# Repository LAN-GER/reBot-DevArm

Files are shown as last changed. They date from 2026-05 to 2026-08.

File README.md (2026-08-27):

# 🦾 reBot-DevArm: Open Source Robotic Arm for All Developers

<p align="center">
  reBot-DevArm Banner
</p>

<p align="center">
    <a href="https://certification.oshwa.org/cn000024.html">
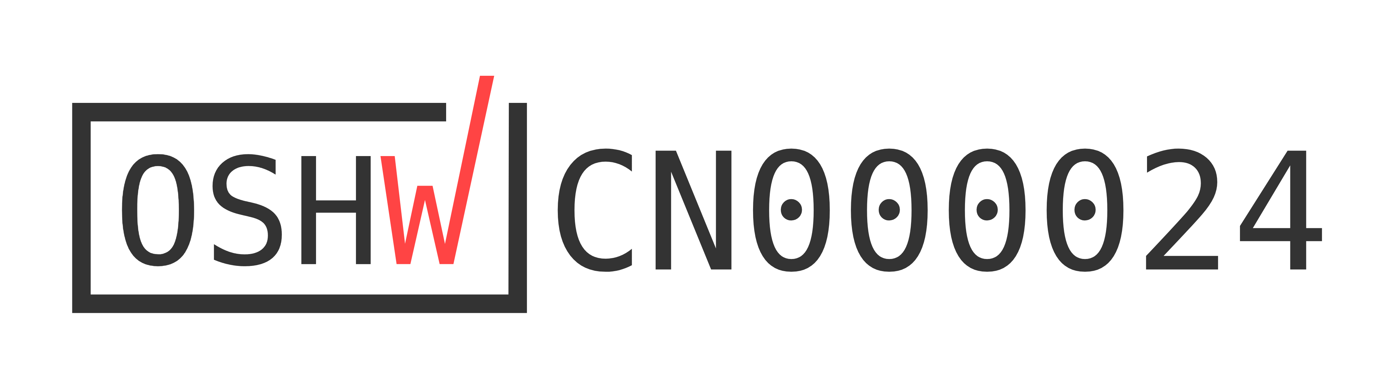
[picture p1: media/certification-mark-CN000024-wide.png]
  
</a>
</p>

<p align="center">
    <a href="./LICENSE">
    
    </a>
    
    </a>
    
    
    
    
</p>

<p align="center">
  <strong>🚀 100% Open Source · Embodied AI · Full Hardware + Software Stack</strong>
</p>

<p align="center">
  <strong>📦 Build your own robotic arm · 🧠 Learn robotics · 🏭 Deploy real applications</strong>
</p>

<table align="center">
  <tr>
    <td>
      <a href="https://www.youtube.com/watch?v=ONbpv3seiG8">
        
      </a>
    </td>
    <td>
      <a href="https://www.youtube.com/watch?v=ONbpv3seiG8">
        About The reBot Arm
      </a>
    </td>
  </tr>
</table>

<p align="center">
  <strong>
    <a href="./README_zh.md">简体中文</a> &nbsp;|&nbsp;
    <a href="./README.md">English</a> &nbsp;|&nbsp;
    <a href="./README_JP.md">日本語</a>&nbsp;|&nbsp;
    <a href="./README_Fr.md">français</a>&nbsp;|&nbsp;
    <a href="./README_es.md">Español</a>
  </strong>
</p>

<p align="center">
<a href="https://discord.gg/AbGuqJhDpQ">
    </a>
<a href="https://wiki.seeedstudio.com/robotics_page/">  
    </a>
</p>

<p align="center">
  <strong>🛒 Official Purchase</strong>
</p>

<table align="center" border="1" cellpadding="12" cellspacing="12">
  <tr>
    <td align="center" width="260" bgcolor="#FFF8F0">
      <b>&#x1F9FE; reBot Arm B601-DM</b><br><br>
      <a href="https://www.seeedstudio.com/reBot-Arm-B601-DM-Assembled-Kit-with-Power-Supply-Bundle.html" target="_blank">
        <big><b>&#x1F6D2; SeeedStudio Bazaar</b></big>
      </a>
        <a href="https://www.amazon.com/dp/B0H2TWVFSW" target="_blank">
        <big><b>&#x1F6D2; Amazon</b></big>
      </a>
      </a>
        <a href="https://de.aliexpress.com/item/1005012108314029.html" target="_blank">
        <big><b>&#x1F6D2; Aliexpress</b></big>
      </a>
    </td>
    <td align="center" width="260" bgcolor="#F0F4FF">
      <b>&#x1F9FE; reBot Arm B601-RS</b><br><br>
      <a href="https://www.seeedstudio.com/reBot-Arm-B601-RS-Bundle-p-6898.html" target="_blank">
        <big><b>&#x1F6D2;  SeeedStudio Bazaar</b></big>
      </a>
      <a href="https://www.aliexpress.us/item/3256812343811970.html?gatewayAdapt=deu2usa4itemAdapt" target="_blank">
        <big><b>&#x1F6D2; Aliexpress</b></big>
      </a>
    </td>
  </tr>
</table>

## 📖 Introduction

**reBot-DevArm (reBot Arm B601 DM and reBot Arm B601 RS)** is a robotic arm project dedicated to lowering the barrier to learning Embodied AI. We focus on **"True Open Source"** — not just the code, we unreservedly open source everything:
- 🦾 **Two versions of the robotic arm**：We will provide all open-source files for two versions of the robotic arm with the same appearance: **Robostride** and **Damiao**.
- 🛠️ **Hardware Blueprints**: Source files for sheet metal parts and 3D printed parts.
- 🔩 **BOM List**: Detailed down to the specifications and purchase links for every single screw.
- 💻 **Software & Algorithms**: Python SDK, ROS1/2, Isaac Sim, LeRobot, etc.

## Get Your Own reBot Arm

- We offer five kit options  at  [Seeedstudio.com](https://www.seeedstudio.com/reBot-Arm-B601-DM-Bundle.html) :
  - **Arm Body Motor Kit**: Includes only motors and wiring harnesses for the robotic arm.
  - **Arm Body Structural Kit**: Includes only mechanical structural components.
  - **Gripper Complete Kit**: Includes motors, wiring harnesses and structural components for the gripper.
  - **Full Kit**: Includes the complete set of the robotic arm body and gripper.
  - **Pre‑assembled Robotic Arm**: Fully assembled finished robotic arm.

- The Seeedstudio kit does not include a power adapter and C-clamps as standard accessories. This arrangement takes into account that users may power the unit via batteries or mount it with a custom DIY base. You may purchase a [power supply separately](https://www.seeedstudio.com/AC-DC-Power-Adapter-IEC-60320-C14-XT30-Female-24V-4-5A-1200mm-L190-W92-5-H36mm-p-6764.html) and [Power Cord](https://www.seeedstudio.com/reServer-AC-US-p-5052.html), or refer to the Mean Well power solution shown at the bottom of our [BOM](./hardware/reBot_B601_DM/readme.md#about-power-supply).

- You can also purchase the [Leader Arm](https://www.seeedstudio.com/Star-Arm-102-p-6765.html?qid=P2U7IG_yskyak5m_1776415593315) and [12V 10A Power Supply](https://www.seeedstudio.com/FY1209900-12V-10A-Power-Adapter-12V-10A-p-6496.html) You may also use the 12VDC power adapter of SO-ARM101 to supply power to the Leader.

-------------------
- For reBot Arm RS Version, We offer five kit options  at  [Seeedstudio.com](https://www.seeedstudio.com/reBot-Arm-B601-RS-Assembled-Kit-with-Gripper-p-6865.html) :
  - **Full Kit**: Includes the unassembled complete set of the robotic arm body and gripper.
  - **Pre‑assembled Robotic Arm**: Fully assembled finished robotic arm.

- We highly recommend using the [Meanwell 48V 12.5A](https://www.amazon.com/sspa/click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) power supply for the RS model. If you need stronger power to unlock its full performance, you may opt for a 48V 25A power adapter.
------------------

## 🗺️ Roadmap & Status

We are committed to continuously maintaining and adapting to mainstream robot development ecosystems. Below is our current adaptation progress and planned release schedule:

### reBot Arm B601 DM
| Supported Ecosystem | Status | Description / Estimated Release Date | Related Documentation |
| :--- | :---: | :--- | :--- |
| **Basic Motor Usage** | ✅ Completed | Basic motion control and API encapsulation | [Damiao Technology](https://wiki.seeedstudio.com/cn/damiao_series/) |
| **Open-Sourcing of the New STEP 3D Structural Parts and BOM** | ✅ Completed | STEP files for all parts in the new version, parts BOM, and reference prices for all machined components | [reBot Arm B601-DM BOM](./hardware/reBot_B601_DM/readme.md) |
| **Reference for Real Machine Performance Testing** | ✅ Completed | Performance Reference of Robotic Arm under Normal and Extreme Operating Conditions |[Performance Testing](./hardware/reBot_B601_DM/performance_testing/Performance_Testing.md) |
| **Assembly Video** | ✅ Completed | Ultra-detailed assembly steps and video | [Getting Started with reBot Arm B601-DM](https://wiki.seeedstudio.com/rebot_b601_dm_getting_started/) |
| **Python SDK** | ✅Continuously optimized, PRs welcome | One-stop integration of motor read/write and control for Robstride, Damiao, Mota, Gaoqing, Hexfellow and other motors. | [Getting Started with Motorbridge](https://motorbridge.seeedstudio.com) and [Web UI](https://rebot-devarm.w0x7ce.eu/)|
| **ROS2 Integration** | ✅ Completed | ROS2 integrated reBot Arm controller with support for kinematics, trajectory planning, and gravity compensation | [reBot Arm B601-DM ROS2 Integration Guide](https://wiki.seeedstudio.com/rebot_arm_b601_dm_ros2_integration/) |
| **Pinocchio Integration** |  ✅ Completed  | Adaptation to the Pinocchio framework, enabling forward/inverse kinematics and gravity compensation for the robotic arm | [Getting Started with Pinocchio for reBot Arm B601-DM](https://wiki.seeedstudio.com/rebot_arm_b601_dm_pinocchio_meshcat/) and [Github repo](https://github.com/vectorBH6/reBotArm_control_py) |
| **Isaac Sim Simulation** | 🚧 In Progress  | Import USD models and enable simulated teleoperation | [delay for add additional courses: 2026.06.20] |
| **LeRobot Integration** | ✅ Completed  | Adaptation to the Hugging Face LeRobot training framework | [Getting Started with LeRobot-based reBot Arm](https://wiki.seeedstudio.com/rebot_arm_b601_dm_lerobot/) |
| **Depth Camera Integration** | ✅ Completed  | Visual Grasping Demonstration Based on YOLO and Depth Camera | [Getting Started with Visual Grasping Demo](https://wiki.seeedstudio.com/rebot_arm_b601_dm_grasping_demo/) |
| **reSpeaker Voice Integration** | ✅ Completed  | Add reSpeaker Flex 4-mic array to build a voice-driven intelligent robot arm control system with spatial awareness | [reBot Arm B601-DM Voice Control](https://wiki.seeedstudio.com/control_rebot_arm_using_voice_with_respeaker_flex/) |
| **Gradual Updates of the Latest Algorithms** | ⏳ Planned | Mainstream algorithms will be updated progressively | Ongoing |
| **Launch of a Series of Completely Free Courses** | ⏳ Planned | Mainstream algorithms will be updated progressively | Ongoing |

#### Contributions from Developers 
| Supported Ecosystem | Authors | Description / Estimated Release Date | Related Documentation or Repository |
| :--- | :---: | :--- | :--- |
| **ROS2 (Humble), third_party integration, URDF / rebotarm_bringup** | [@danieldoradotalaveron-rb](https://github.com/danieldoradotalaveron-rb) | 1. **Passive diagnostics monitor** (`rebotarm_monitor_ros2`): `/diagnostics` overlay for `rqt_robot_monitor`, serial/CAN-aware aggregator;<br>2. **Safe park & shutdown**: Capture rest pose on connect, slow return on shutdown or `/rebotarm/park` to prevent sudden drop;<br>3. **Gravity compensation (smooth stop)**: MIT ramp-out when exiting gravity compensation to eliminate clack, jerk and instability during pos/vel handoff;<br>4. **Gamepad teleop with IK/FK and safety measures**: Gamepad control for end-effector via IK, live robot state visualization in RViz (simulation-only test);<br>5. **D405 eye-in-hand TF**: Xacro setup under `end_link` in `rebotarm_bringup` for RViz visualization & TF only (no driver/depth/intrinsics). Mount pose adjustable via launch file, bracket calibration not completed. Teleop FK/IK uses arm-only `fixend_core` URDF, full xacro for RSP/RViz. | [rebotarm_monitor_ros2](https://github.com/danieldoradotalaveron-rb/rebotarm_monitor_ros2)、[reBotArmController_ROS2](https://github.com/danieldoradotalaveron-rb/reBotArmController_ROS2) |

### reBot Arm B601 RS

| Supported Ecosystem | Status | Description / Estimated Release Date | Related Documentation |
| :--- | :---: | :--- | :--- |
| **Basic Motor Usage** | ✅ Completed | Basic motion control and API encapsulation | [Robstride](https://wiki.seeedstudio.com/cn/robstride_control/) |
| **Open-Sourcing of the New STEP 3D Structural Parts and BOM** | ✅ Completed | STEP files for all parts in the new version, parts BOM, and reference prices for all machined components | [reBot Arm B601-RS BOM](./hardware/reBot_B601_RS/README.md) |
|**Getting Started**| ✅ Completed | Quick start of B601-RS| [Getting Started with reBot Arm B601-RS](https://wiki.seeedstudio.com/rebot_b601_rs_getting_started/) |
| **Assembly Video** | ✅ Completed | Ultra-detailed assembly steps and video | [reBot Arm B601-RS Assembly Video](https://wiki.seeedstudio.com/rebot_b601_rs_getting_started/) |
| **ROS2 (Humble)** | ✅ Completed | ROS2 integrated reBot Arm controller with support for kinematics, trajectory planning, gravity compensation and MoveIt2 | [reBot Arm B601-DM ROS2 Integration Guide](https://wiki.seeedstudio.com/rebot_arm_b601_rs_ros2_integration/) |
| **LeRobot Integration** |✅ Completed| Adaptation to the Hugging Face LeRobot training framework | [Getting Started with LeRobot-based reBot Arm](https://wiki.seeedstudio.com/rebot_arm_b601_rs_lerobot/) |
| **Pinocchio Integration** | ✅ Completed | Adaptation to the Pinocchio framework, enabling forward/inverse kinematics and gravity compensation for the robotic arm | [Getting Started with Pinocchio for reBot Arm B601-DM](https://wiki.seeedstudio.com/rebot_arm_b601_rs_pinocchio_meshcat/) and [Github repo](https://github.com/vectorBH6/reBotArm_control_py) |
| **Depth Camera Integration** | ✅ Completed  | Visual Grasping Demonstration Based on YOLO and Depth Camera | [Getting Started with Visual Grasping Demo](https://wiki.seeedstudio.com/rebot_arm_b601_dm_grasping_demo/) |
| **Isaac Sim Simulation** |✅ Completed  | Import USD models and enable simulated teleoperation | [Github Repo](https://github.com/Seeed-Projects/reBot-Isaacsim) |
| **Gradual Updates of the Latest Algorithms** | ⏳ Planned | Mainstream algorithms will be updated progressively | On going |
| **Launch of a Series of Completely Free Courses** | ⏳ Planned | Mainstream algorithms will be updated progressively | Ongoing |

---

## ⚙️ Hardware Specifications

reBot-DevArm is designed for desktop Embodied AI applications, balancing payload capacity with flexibility.

| Parameter | reBot Arm B601-DM | reBot Arm B601-RS|
| :--- | :--- | :--- |
| **Payload** | 1.5kg | **2.5kg** |
| **Recommended Workspace** | 70% arm reach workspace | 70% arm reach workspace |
| **Max Reach** | 767 mm | **754 mm** |
| **Weight** | **Approx. 4.5 kg** | Approx. 6.7 kg |
| **Repeatability** | < 0.2 mm | < 0.2 mm |
| **Degrees of Freedom (DOF)** | 6 DOF + 1 Gripper | 6 DOF + 1 Gripper |
| **Supported Platforms/Ecosystems** | ROS1, ROS2, LeRobot, Pinocchio, Isaac Sim, Python SDK | ROS1, ROS2, LeRobot, Pinocchio, Isaac Sim, Python SDK |
| **Supply Voltage** | DC 24V | DC 48V |

## Feedback from the community
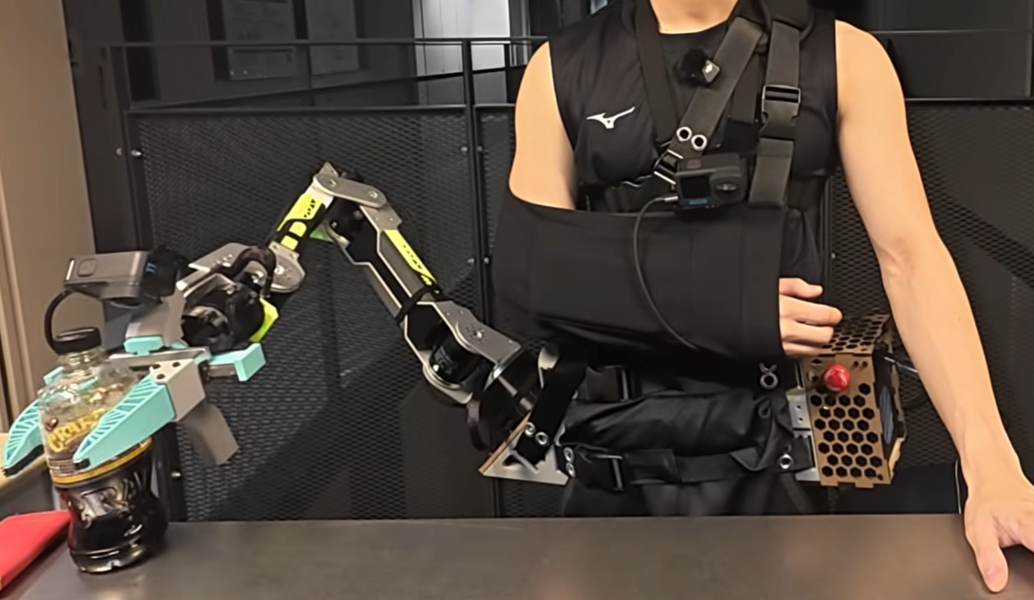
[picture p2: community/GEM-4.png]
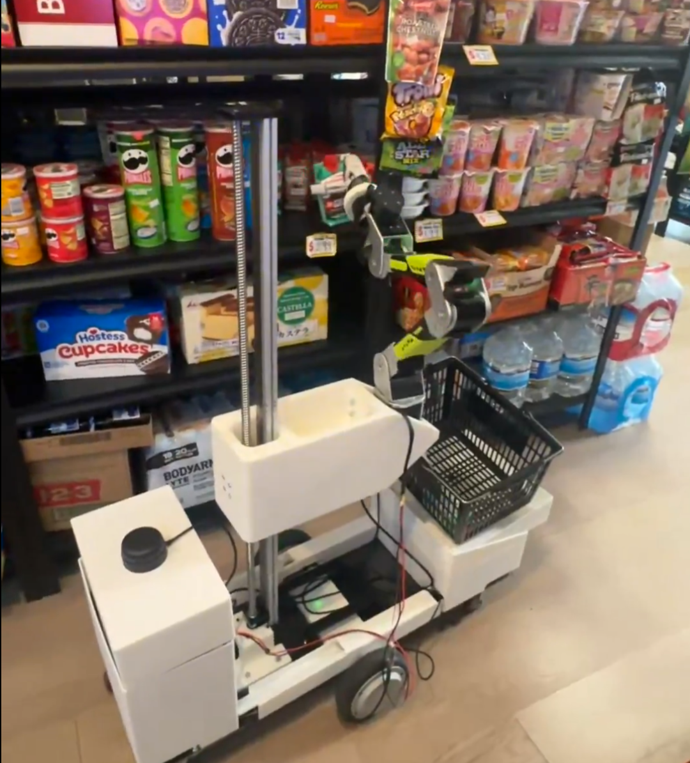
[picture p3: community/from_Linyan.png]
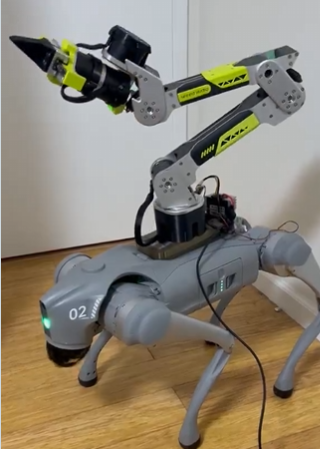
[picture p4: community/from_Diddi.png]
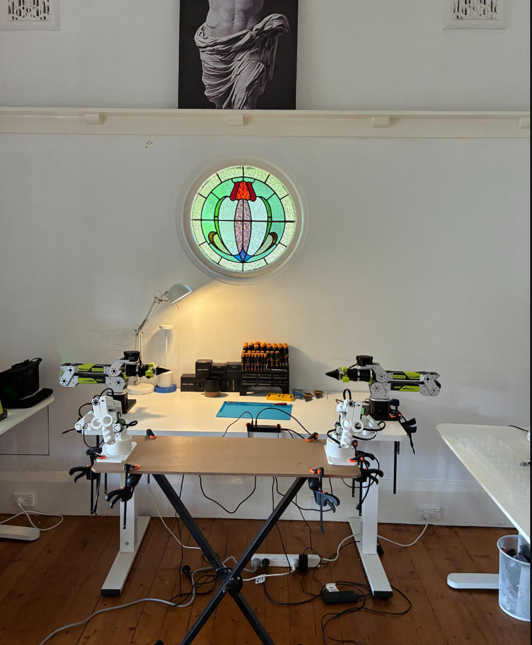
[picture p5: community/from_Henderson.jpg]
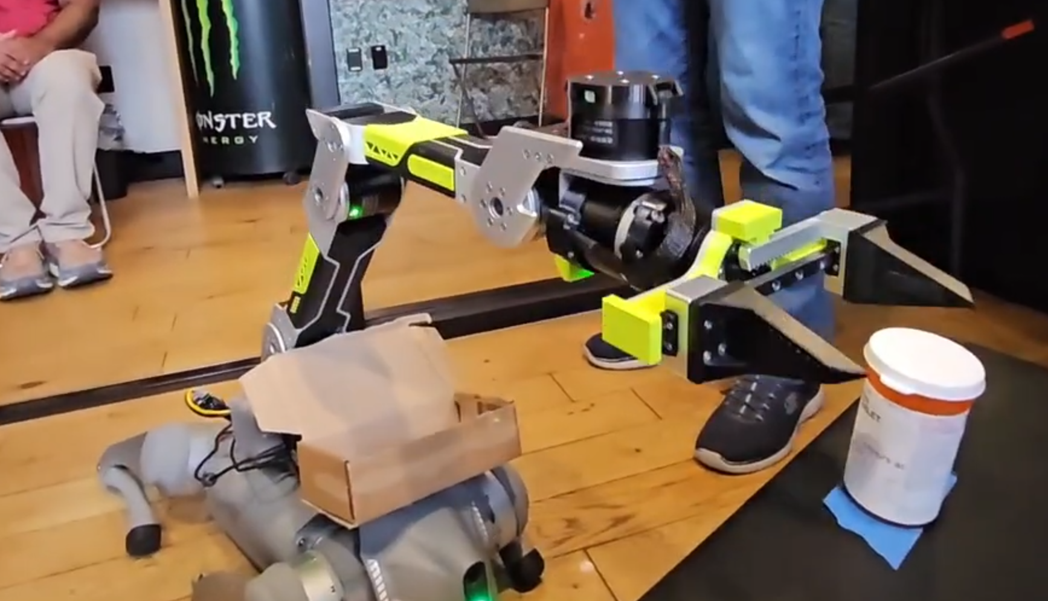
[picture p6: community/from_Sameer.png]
|  |  |  |  | |
| --- | --- | --- | --- |  --- |
| [From GEM-4: Gemma Embodied 4 Physical Assistance](https://www.kaggle.com/competitions/gemma-4-good-hackathon/writeups/new-writeup-1778618527713) | [From Linyan Fu](https://x.com/Linyan_Fu/status/2056383947341525180)  and [Apheth D Almeida](https://x.com/Apheth_DAlmeida/status/2053503164507476096)| [From Dhruv Diddi](https://x.com/DhruvDiddi/status/2046605015008383284)  | [From Ed Henderson](https://x.com/ed0henderson/status/2055076839002095743)  | From Sameer | 
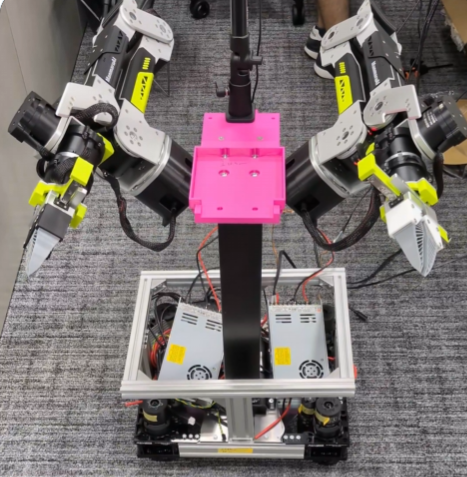
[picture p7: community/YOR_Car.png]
|  |  |  |  |  |
| [From Binh_Pham](https://x.com/pham_blnh/status/2061994096374505710) | [From FangTianChongHui](https://www.instagram.com/reel/DY7Ny8OPjVu/?utm_source=ig_web_copy_link&igsh=NTc4MTIwNjQ2YQ==)| [Xense YaoLin Dong](https://x.com/dong1505lin)  | [From Ed Henderson](https://x.com/ed0henderson/status/2055076839002095743)  |  [From yoshikai_man](https://x.com/yoshikai_man/status/2079938975398244705)  | 

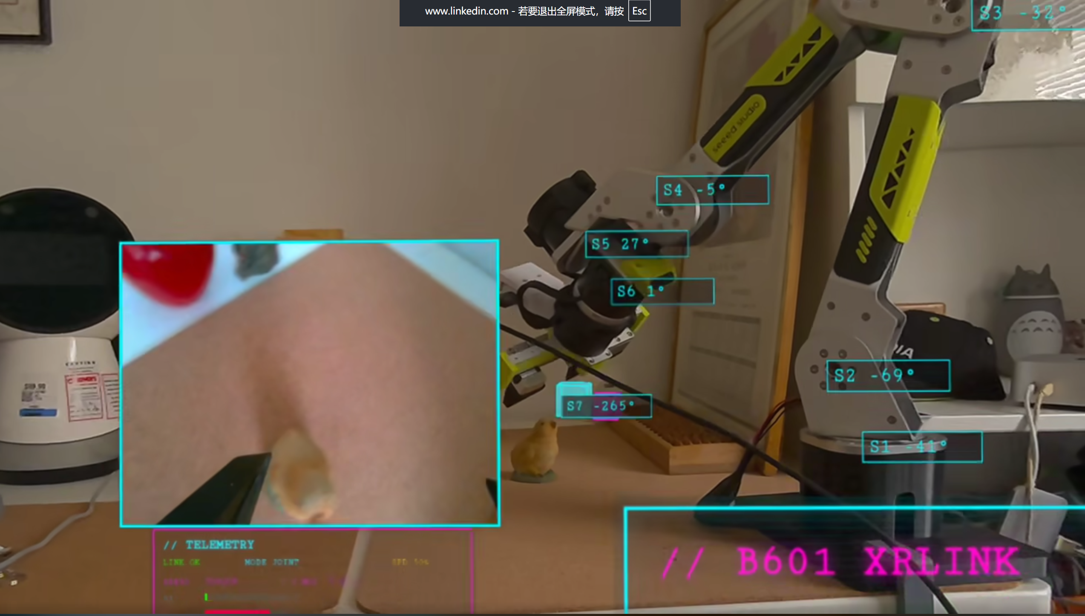
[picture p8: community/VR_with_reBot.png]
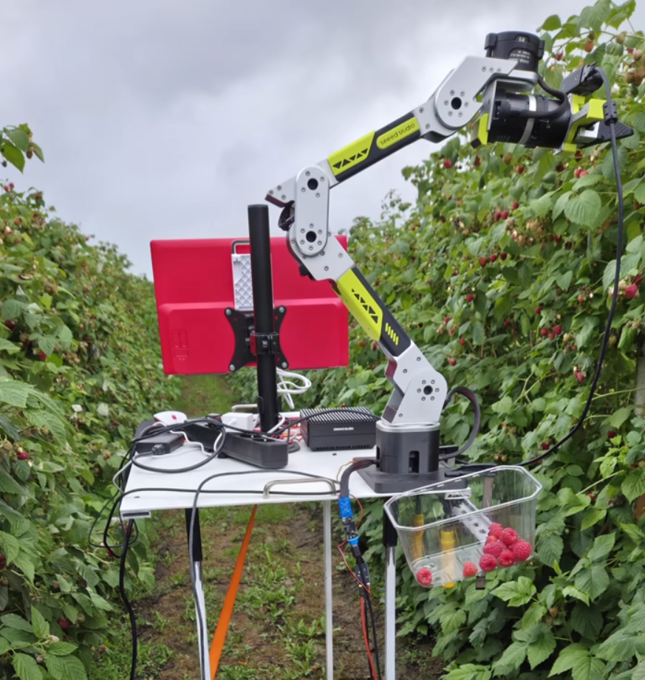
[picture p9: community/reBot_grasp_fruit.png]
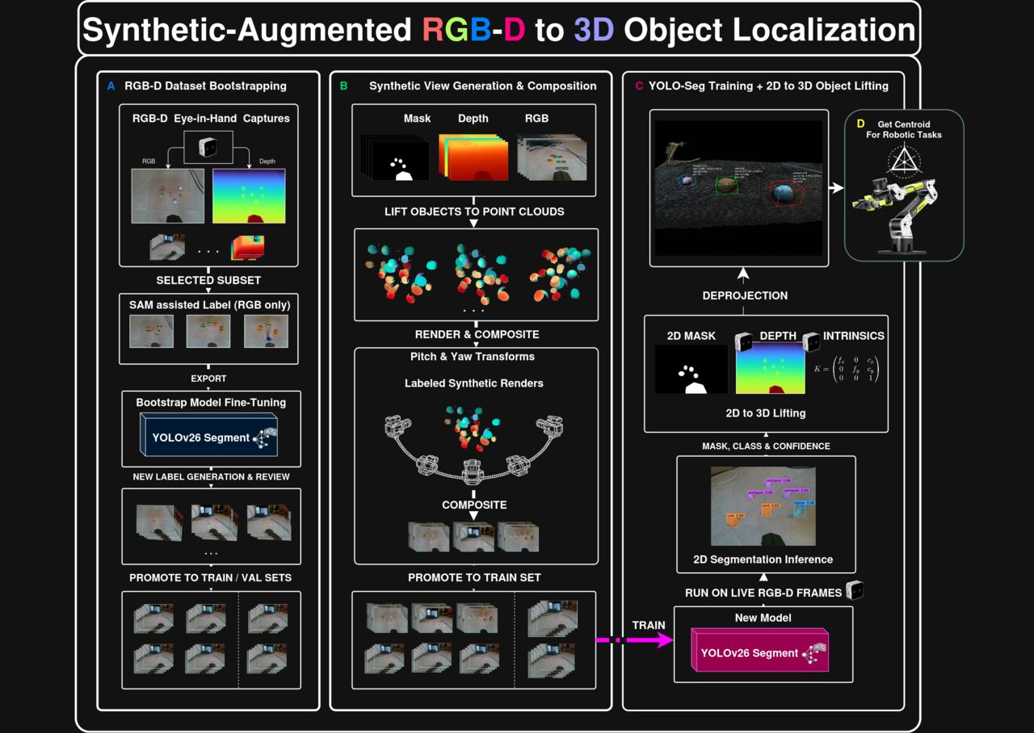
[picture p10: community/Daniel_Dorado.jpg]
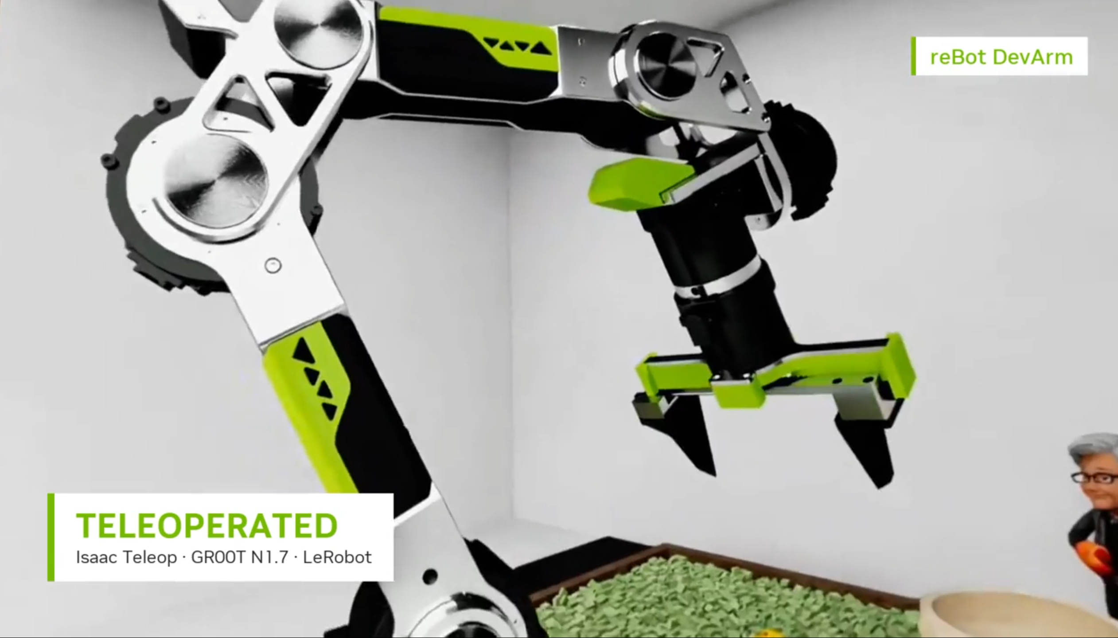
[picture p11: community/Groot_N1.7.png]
|  |  |  |  |  |
| --- | --- | --- | --- |  --- |
| [From hei-rebot-lift](https://github.com/lipengdong/hei-rebot-lift) | [From Martin Kemka](https://www.linkedin.com/posts/activity-7484390995862781952-TX4m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)| [From Kamil Buczyński](https://www.linkedin.com/posts/kamil-buczy%C5%84ski-102843301_seeedstudio-rebotarm-seeedprojectofthemonth-ugcPost-7485297094715461633-RV_6/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)  | [From Daniel Dorado](https://www.linkedin.com/posts/doradodaniel_computervision-spatialai-sim2real-share-7474727487374184448-NhwX/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)  |  [From Asier](https://www.linkedin.com/posts/asierarranz_nvidia-physicalai-isaaclab-ugcPost-7480271721942417408-YNwu/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)  | 

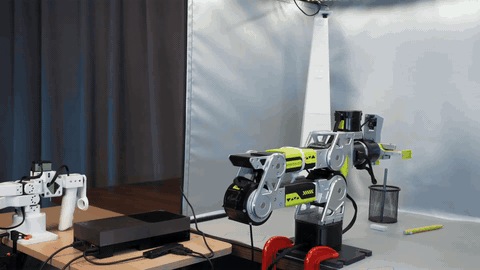
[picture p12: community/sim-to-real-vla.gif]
|  |
| --- |
| [Seeed reBot Arm and NVIDIA Isaac Sim-to-Real VLA Course](https://www.seeedstudio.com/sim-to-real-with-seeed-rebot-and-nvidia-isaac) |

## 🧹Optional Hardware
###  Wirst Camera Mount
| 32×32 UVC  | Intel D435i | Intel D405 & Gemini 305 | Gemini 2|
| --- | --- | --- | --- |
|  |  |   |  | 
| [STEP](/hardware/reBot_B601_DM/3D_Printed_Parts/UVC32_mount.step) | [STEP](/hardware/reBot_B601_DM/3D_Printed_Parts/D435_Gemini2_Mount.step) | [STEP](/hardware/reBot_B601_DM/3D_Printed_Parts/D405_305_Mount.step) |[STEP](/hardware/reBot_B601_DM/3D_Printed_Parts/D435_Gemini2_Mount.step) |

###  Compatible with Leader Arm
| Star Arm 102-LD  |  Open to compatibility integration  | 
| --- | --- |
|    |Comming soon| 
|  [Github repo](https://github.com/servodevelop/Star-Arm-102) |Comming soon |

### DIY Finger
| Soft Finger  |  Open to compatibility integration  | 
| --- | --- |
|    |Comming soon| 
| [Finger Mount(ABS/PLA)](/hardware/reBot_B601_DM/3D_Printed_Parts/Soft_Gripper_Mount.step) and [Finger (TPU 95+)](/hardware/reBot_B601_DM/3D_Printed_Parts/Soft_Gripper_Finger.step)  |Coming soon |

### Recommended Optional Hardware
<table>
  <thead>
    <tr>
      <th>Category</th>
      <th>Type</th>
      <th>Preview</th>
      <th>Product</th>
      <th>Link</th>
    </tr>
  </thead>
  <tbody>
    <tr>
      <td rowspan="8" align="center"><strong>Camera</strong></td>
      <td rowspan="6" align="center">Depth Camera</td>
      <td align="center">Orbbec Gemini 2 3D Camera</td>
      <td><strong>Orbbec Gemini 2 3D Camera</strong></td>
      <td><a href="https://www.seeedstudio.com/Orbbec-Gemini-2-3D-Camera-p-6464.html">Seeed Studio</a></td>
    </tr>
    <tr>
      <td align="center">Orbbec Gemini 336 Depth Camera</td>
      <td><strong>Orbbec Gemini 336 Depth Camera</strong></td>
      <td><a href="https://www.seeedstudio.com/Orbbec-Gemini-336-3D-Camera-3D-p-6662.html">Seeed Studio</a></td>
    </tr>
    <tr>
      <td align="center">Orbbec Gemini 335LG 3D Camera</td>
      <td><strong>Orbbec Gemini 335LG 3D Camera</strong></td>
      <td><a href="https://www.seeedstudio.com/Orbbec-Gemini-335LG-3D-Camera-p-6541.html">Seeed Studio</a></td>
    </tr>
    <tr>
      <td align="center">SLAMTEC Aurora S, Integrated Spatial Perception Module</td>
      <td><strong>SLAMTEC Aurora S</strong><br></td>
      <td><a href="https://www.seeedstudio.com/SLAMTEC-Aurora-S-AI-Integrated-Spatial-Perception-System-p-6669.html">Seeed Studio</a></td>
    </tr>
    <tr>
      <td align="center">Intel RealSense Depth Camera D435i</td>
      <td><strong>Intel RealSense Depth Camera D435i</strong></td>
      <td><a href="https://www.seeedstudio.com/Intel-RealSense-Depth-Camera-D435i-p-4423.html">Seeed Studio</a></td>
    </tr>
    <tr>
      <td align="center">RealSense Depth Camera D405</td>
      <td><strong>RealSense Depth Camera D405</strong></td>
      <td><a href="https://www.seeedstudio.com/RealSense-D405-3D-Camera-p-6758.html">Seeed Studio</a></td>
    </tr>
    <tr>
      <td rowspan="2" align="center">Monocular Camera</td>
      <td align="center">Sensing SG3S-ISX031C-GMSL2F 3MP GMSL2 Camera</td>
      <td><strong>Sensing SG3S-ISX031C-GMSL2F 3MP GMSL2 Camera</strong></td>
      <td><a href="https://www.seeedstudio.com/SG3S-ISX031C-GMSL2F-p-6245.html">Seeed Studio</a></td>
    </tr>
    <tr>
      <td align="center">ET-S231 Megapixel 120 Degree Wide-Angle 1080P USB Camera Module</td>
      <td><strong>ET-S231 Megapixel 120 Degree Wide-Angle 1080P USB Camera Module</strong></td>
      <td><a href="https://www.seeedstudio.com/ET-S231-120-USB-Camera-p-6683.html">Seeed Studio</a></td>
    </tr>
    <tr>
      <td rowspan="2" align="center"><strong>Microphone</strong></td>
      <td rowspan="2" align="center">Mic Array</td>
      <td align="center">reSpeaker Flex XVF3800 Circular-4 with XIAO ESP32S3</td>
      <td><strong>reSpeaker Flex XVF3800 Circular-4 with XIAO ESP32S3</strong><br><sub>AI Mic Array for Robotics and Embodied AI</sub></td>
      <td><a href="https://www.seeedstudio.com/reSpeaker-Flex-XVF3800-Circular-4-with-XIAO-ESP32S3-p-6739.html">Seeed Studio</a></td>
    </tr>
    <tr>
      <td align="center">reSpeaker XMOS XVF3800</td>
      <td><strong>reSpeaker XMOS XVF3800</strong><br><sub>AI-powered 4-Mic Array for Clear Voice Even in Noise</sub></td>
      <td><a href="https://www.seeedstudio.com/ReSpeaker-XVF3800-USB-Mic-Array-p-6488.html">Seeed Studio</a></td>
    </tr>
    <tr>
      <td rowspan="2" align="center"><strong>Controller</strong></td>
      <td rowspan="2" align="center">Edge Controller</td>
      <td align="center">reComputer J3011-Orin Nano 8GB</td>
      <td><strong>reComputer J3011-Orin Nano 8GB</strong></td>
      <td><a href="https://www.seeedstudio.com/reComputer-J3011-p-5590.html">Seeed Studio</a></td>
    </tr>
    <tr>
      <td align="center">NVIDIA Jetson AGX Thor Developer Kit</td>
      <td><strong>NVIDIA Jetson AGX Thor Developer Kit</strong></td>
      <td><a href="https://www.seeedstudio.com/NVIDIA-Jetson-AGX-Thor-Developer-Kit-p-9965.html">Seeed Studio</a></td>
    </tr>
  </tbody>
</table>

---

### 🎓 Full-Stack Robotics Ecosystem
reBot-DevArm is not just a robotic arm, but a robotics learning community. We share the following general tutorials for free:

#### 🖥️ Edge Computing & Master Control
*    —— **AI Inference & Compute Core**
*    —— **General Linux Development Environment**
*    —— **Low-power Wireless Control Node**

#### 📡 Sensors & Peripherals
*   **🚗 Motors & Servos**: [Damiao / Gogo / Robstride / Mita / Feite / Fashion Star](https://wiki.seeedstudio.com/robotics_page/)
*   **👁️ Visual Perception**: [Depth Cameras / LiDAR / Vision Algorithms](https://wiki.seeedstudio.com/robotics_page/)
*   **👂 Voice Interaction**: [reSpeaker Mic Arrays/Voice Control/Spatial Awareness(DoA)](https://wiki.seeedstudio.com/control_rebot_arm_using_voice_with_respeaker_flex/)
*   **🧭 Motion & Attitude**: [IMU (6-axis/9-axis) / Gyroscopes / Magnetometers](https://wiki.seeedstudio.com/Sensor_accelerometer/)
*   **🤖 Comprehensive Kits**: [More Robotics Sensors & Driver Examples](https://wiki.seeedstudio.com/robotics_page/)

> 👉 **[Click to Enter Wiki Knowledge Base](https://wiki.seeedstudio.com/)** (All tutorials are free to view)

---

## 🙌 References & Acknowledgments
The path of open source is never lonely. The birth of the reBot-DevArm project would not be possible without the full support of Seeed Studio, the global open source community, and excellent hardware partners. We pay our highest respects to the following projects and teams:

### 🌍 Ecosystem & Software Support
*   **[Seeed Studio](https://www.seeedstudio.com/)** - Providing comprehensive hardware supply chain and technical support.
*   **[Hugging Face LeRobot](https://github.com/huggingface/lerobot)** - An excellent end-to-end robot learning framework.
*   **[NVIDIA Isaac Sim](https://developer.nvidia.com/isaac/sim)** - A powerful robot simulation and synthetic data platform.

### ⚙️ Core Hardware Partners
Thanks to the following manufacturers for providing high-performance motor and actuator solutions:
*   **[Damiao Technology](https://www.damiaokeji.com/)**
*   **[Robstride](https://robstride.com/)**
*   **[Fashion Star](https://fashionstar.com.hk/wiki/)**

### 💡 Inspiration
This project is deeply inspired by the following excellent open source projects:
*   **[SO-ARM100](https://github.com/TheRobotStudio/SO-ARM100/tree/main)**
*   **[Mobile ALOHA](https://github.com/tonyzhaozh/aloha)**
*   **[Dummy-Robot (Zhihui Jun)](https://github.com/peng-zhihui/Dummy-Robot)**
*   **[OpenArm](https://openarm.dev/)**
*   **[I2RT](https://i2rt.com/)**
*   **[TRLC-DK1](https://github.com/robot-learning-co/trlc-dk1)**

### 🎃 Prototype Contributors
- **SeeedStudio AI Robotics Team's**: Yaohui Zhu (yaohui.zhu@seeed.cc)
- **SeeedStudio STU**: Wentao Dong
- **SeeedStudio STU**: Weiwei Xu
- **SeeedStudio Purchasing Department**: Fengqun Peng

### 👥 Contributors

## Our Top Contributors 
<p align="center"><a href="https://github.com/Seeed-Projects/reBot-DevArm/graphs/contributors">
  
</a></p>

*Coming soon... Welcome to submit PRs to become a contributor!*

## Star History

<p align="center">
<picture>
  <source media="(prefers-color-scheme: dark)" 
          srcset="assets/star-history/star-history-dark.svg">

  <source media="(prefers-color-scheme: light)" 
          srcset="assets/star-history/star-history-light.svg">

  
</picture>
</p>

# reBot-DevArm Project License

- **Hardware Design** © 2026 Seeed Studio Co., Ltd. (SeeedStudio), open-sourced under [CERN-OHL-W-2.0](https://ohwr.org/cern_ohl_w_v2.txt)
- **Firmware Code** © 2026 Seeed Studio Co., Ltd. (SeeedStudio), open-sourced under [Apache-2.0](https://www.apache.org/licenses/LICENSE-2.0)

## Rights and Restrictions

Dear developers and industry experts, the reBot Arm robotic arm project has always adhered to the core philosophy of **Agility, Openness, Responsibility, and Symbiosis** to serve the developer community. Our vision is to enable every enthusiast to systematically master the hardware architecture and software principles of robotic arms, and to gain an immersive experience with cutting-edge embodied intelligence algorithms through the reBot project.

For the first five months since launch, the project has been using the **CC BY-SA NC (Non-Commercial) open source license**. The original intention was to allow all developers and contributors to focus on iterating and improving the product during its initial, less mature phase, free from commercial concerns, and to fully dedicate themselves to project co-construction and optimization.

After months of in-depth product polishing and technical refinement by Seeed Studio, **effective May 11, 2026**, the reBot Arm project has officially transitioned from the CC BY-SA NC license to the **CERN-OHL-W 2.0 open source license**.

From this point forward, the project achieves **100% full-stack open source (both hardware and software), granting full commercial compliance and usage rights for all scenarios**.

We look forward to your continued participation with an inclusive and collaborative spirit, to sustain, maintain, and deepen the reBot Arm open source community, to share the fruits of open source, and together build an ecosystem for embodied intelligence.

This project uses different open source licenses for Hardware and Software. Please confirm the license terms applicable to the part you are using.

| Item / License | reBot Hardware: CERN-OHL-W-2.0 | reBot Software SDK: Apache-2.0 |
| --- | --- | --- |
| **✅ Commercial Use Allowed** | ✅ Allowed | ✅ Allowed |
| **✅ Modification Allowed** | ✅ Allowed | ✅ Allowed |
| **✅ Redistribution Allowed** | ✅ Allowed | ✅ Allowed |
| **✅ Closed-source Integration/Redistribution** | ❌ Conditional (see [CERN-OHL-W-2.0](https://ohwr.org/cern_ohl_w_v2.txt) for details) | ✅ Allowed (no need to disclose modified code) |
| **⚠️ Copyright Retention Required** | ✅ Required | ✅ Required |
| **⚠️ License Text Retention Required**  | ✅ Required | ✅ Required |
| **⚠️ Modification Notice Required** | ✅ Required (with date and description) | ✅ Required (with modification description) |
| **⚠️ Patent Grant** | ✅ Explicit patent grant (see [CERN-OHL-W-2.0](https://ohwr.org/cern_ohl_w_v2.txt) for details) | ✅ Explicit patent grant |
| **⚠️ Source Provision upon Distribution** | ✅ **Must** provide hardware "Complete Source" | ❌ No mandatory source provision requirement |
| **⚠️ External/Closed Module Compatibility** | ✅ Allowed (Weakly Reciprocal feature) | ✅ Fully allowed |
| **🔗 Relationship with Other Components/Modules** | Independent interface modules (External Material) may retain original closed license | No restrictions, can link with code under any license |
| **📄 Official License Full Text** | [CERN-OHL-W-2.0](https://ohwr.org/cern_ohl_w_v2.txt) | [Apache-2.0](https://www.apache.org/licenses/LICENSE-2.0) |

## ☎ Contact Us
- **Open‑Source Progress & Technical Support**-Yaohui: yaohui.zhu@seeed.cc
- **Future Collaboration & Customization**-Elaine: elaine.wu@seeed.cc

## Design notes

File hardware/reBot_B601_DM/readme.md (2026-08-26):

# 🤖 reBot DevArm Open Source Hardware Specification

<p align="center">
  reBot-DevArm Banner
</p>
<p align="center">
  <strong>
    <a href="./readme_zh.md">简体中文</a> &nbsp;|&nbsp;
    <a href="./readme.md">English</a> &nbsp;|&nbsp;
    <a href="./readme_jp.md">日本語</a>&nbsp;|&nbsp;
    <a href="./readme_fr.md">français</a>&nbsp;|&nbsp;
    <a href="./readme_es.md">Español</a>
  </strong>
</p>

| Date | Version | File Name | Changelog |
|---|---|---|---|
|  2026-03-31 | v1.0 |  reBot_B601_DM_v1.0_20260331.step  | Initial upload |
|  2026-04-25 | v1.1 |  reBot_B601_DM_v1.1_20260425.step  | Added Cable Restraint for the 3 end joint motors to prevent loosening and disconnection. Fixed Joint 1 model from 4310 to 4340P. Added CNC part 02_Base_Reinforcement_Part.step at the bottom to enhance base rigidity. |

This BOM is for the reBot Arm B601 DM robotic arm, which uses Damiao 43 series motors. The other version, reBot Arm B601 RS, uses RobStride motors; [see the BOM here](../reBot_B601_RS/README.md).

# 📦 File Structure
*   3D_Printed_Parts/: Step files for all 3D printed parts.
*   Metal_Parts/: Step files for all CNC machined metal parts.
*   Purchased_Parts/: Step files for all purchased components.
*   reBot_B601_DM_v1.1_20260415.step: Full robotic arm assembly file.

# 🛒[Gets All Parts](https://www.seeedstudio.com/reBot-Arm-B601-DM-Bundle.html)
- We offer five kit options:
  - **Arm Body Motor Kit**: Includes only motors and wiring harnesses for the robotic arm.
  - **Arm Body Structural Kit**: Includes only mechanical structural components.
  - **Gripper Complete Kit**: Includes motors, wiring harnesses and structural components for the gripper.
  - **Full Kit**: Includes the complete set of the robotic arm body and gripper.
  - **Pre‑assembled Robotic Arm**: Fully assembled finished robotic arm.

# 📊 Bill of Materials (BOM)

> [!WARNING]
> Declaration: The published BOM does **not** represent the final shipping version from Seeed. This open-source v1.1 is optimized for developers to reproduce at minimal cost, with some non-essential details simplified.
> The final Seeed production version will include metal laser engraving for foolproofing, some 3D printed parts will be replaced with metal for durability, clearances and machining tolerances will be adjusted for factory variation (balancing precision and cost), and custom wiring (e.g., braided sleeve protection) will be added at extra cost. However, the mechanical structure remains identical.

---

## 🖨️ 3D Printed Parts

| Part Description | Image | File Name | Material | Qty | Notes |
|---|---|---|---|---|---|
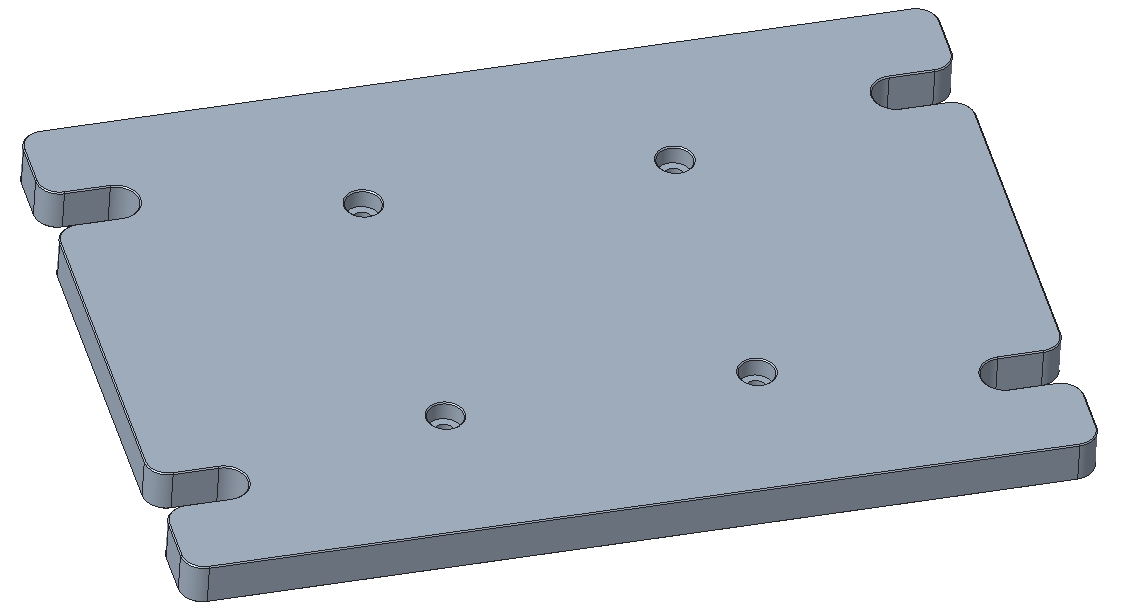
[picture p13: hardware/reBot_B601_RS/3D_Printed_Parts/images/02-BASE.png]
| Robotic Arm Base Platform |  | 01_BASE_Plate.step | Bambu ABS Black | 1 | 0.4 nozzle, 0.2 layer height, 30% infill |
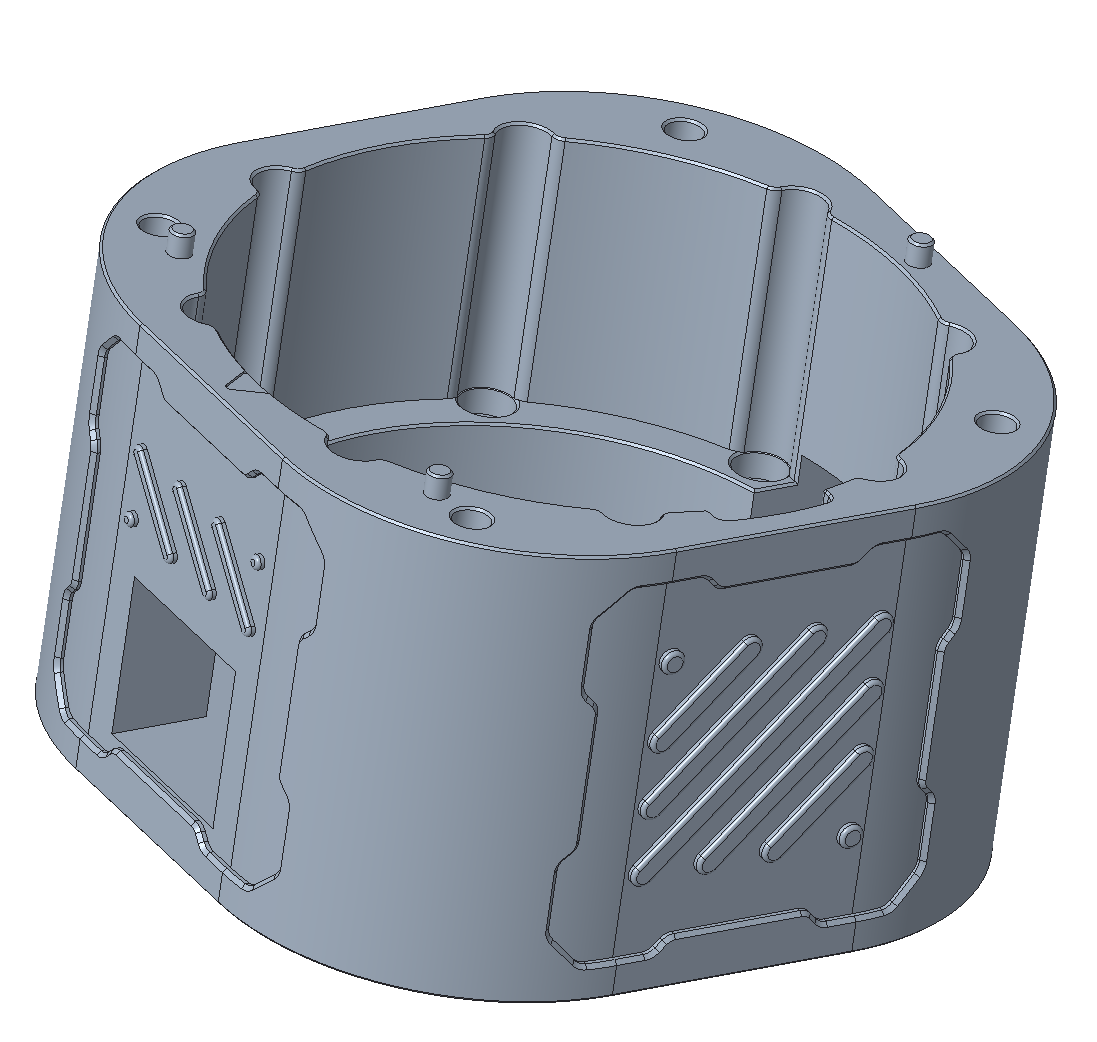
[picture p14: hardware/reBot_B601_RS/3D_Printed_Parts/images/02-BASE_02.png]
| Robotic Arm Base Link |  | 01_BASE_Link.step | Bambu ABS Black | 1 | 0.4 nozzle, 0.2 layer height, 30% infill |
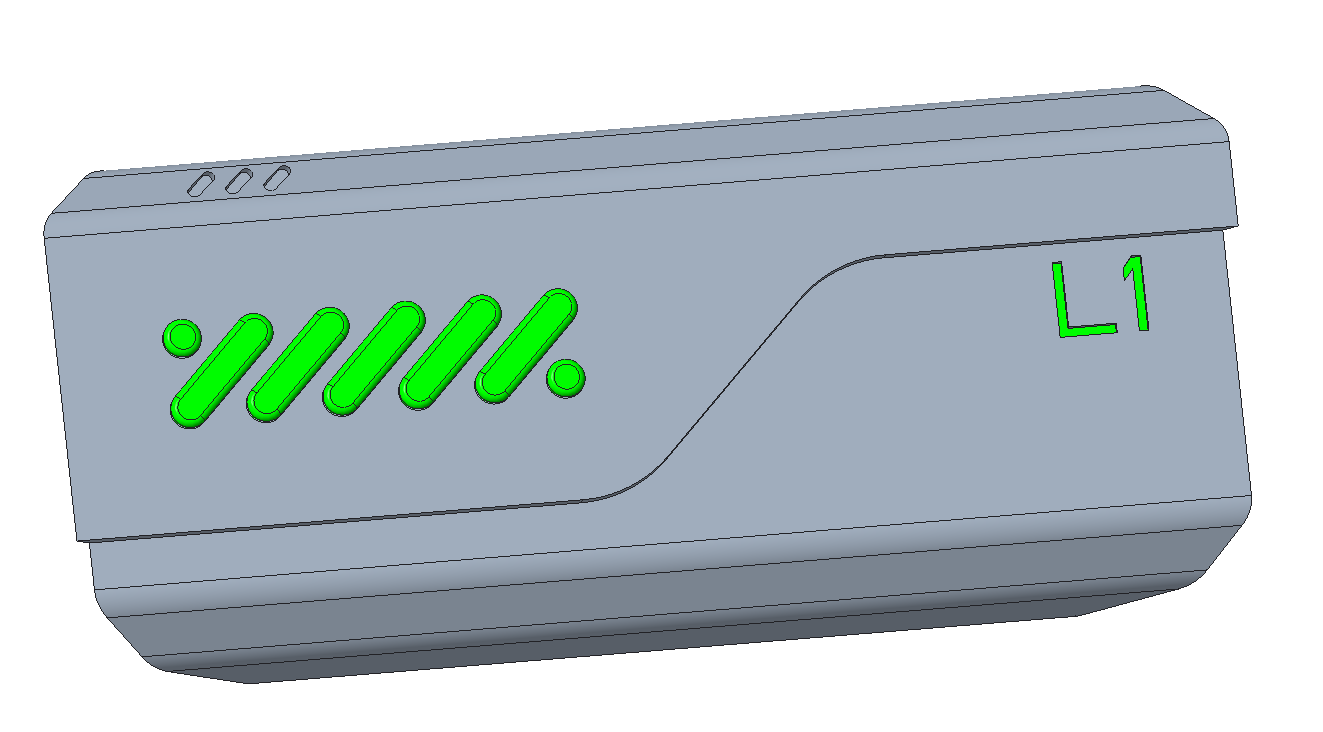
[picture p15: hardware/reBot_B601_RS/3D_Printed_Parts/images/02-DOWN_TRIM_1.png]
| Upper Arm Left Filler |  | 01_Upper_Arm_Fuller_L.step | Bambu PLA Black & Green | 1 | 0.4 nozzle, 0.2 layer height, 15% infill |
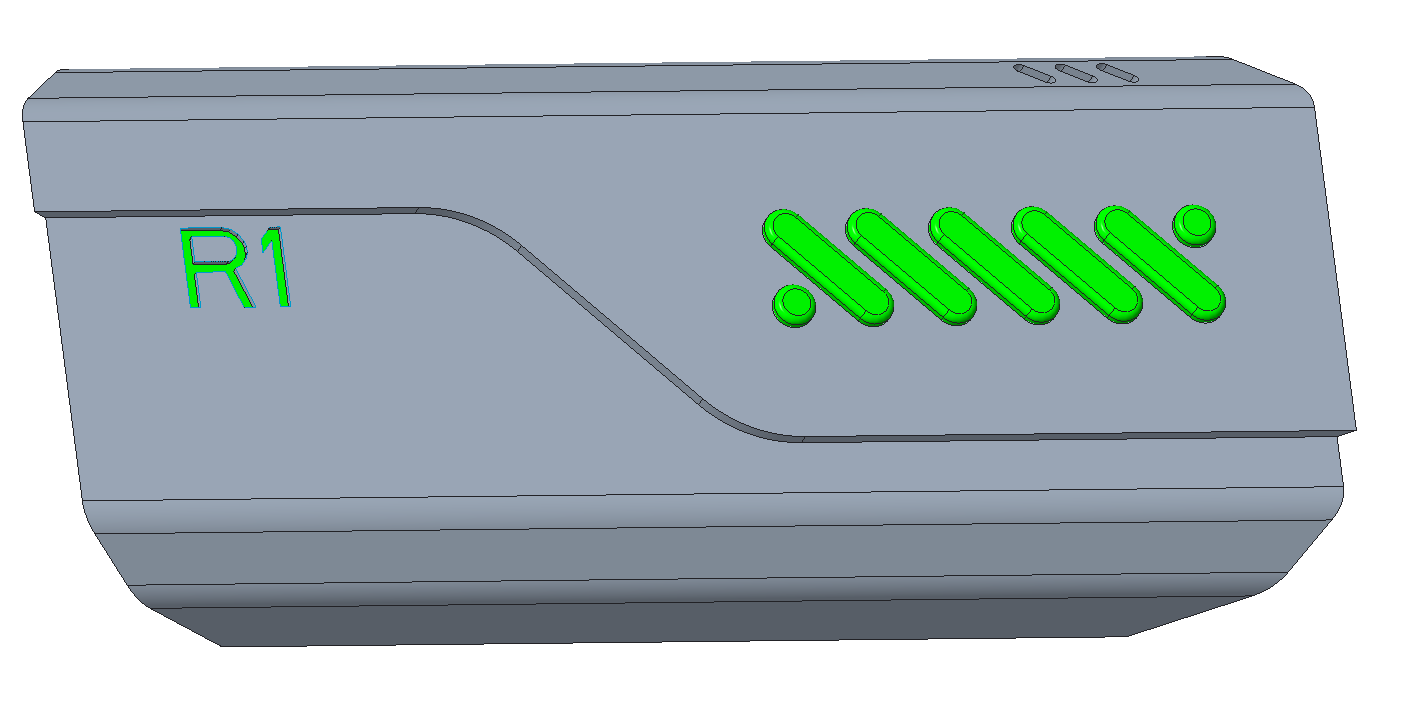
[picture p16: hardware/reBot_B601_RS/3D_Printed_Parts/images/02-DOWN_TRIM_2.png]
| Upper Arm Right Filler |  | 01_Upper_Arm_Fuller_R.step | Bambu PLA Black & Green | 1 | 0.4 nozzle, 0.2 layer height, 15% infill |
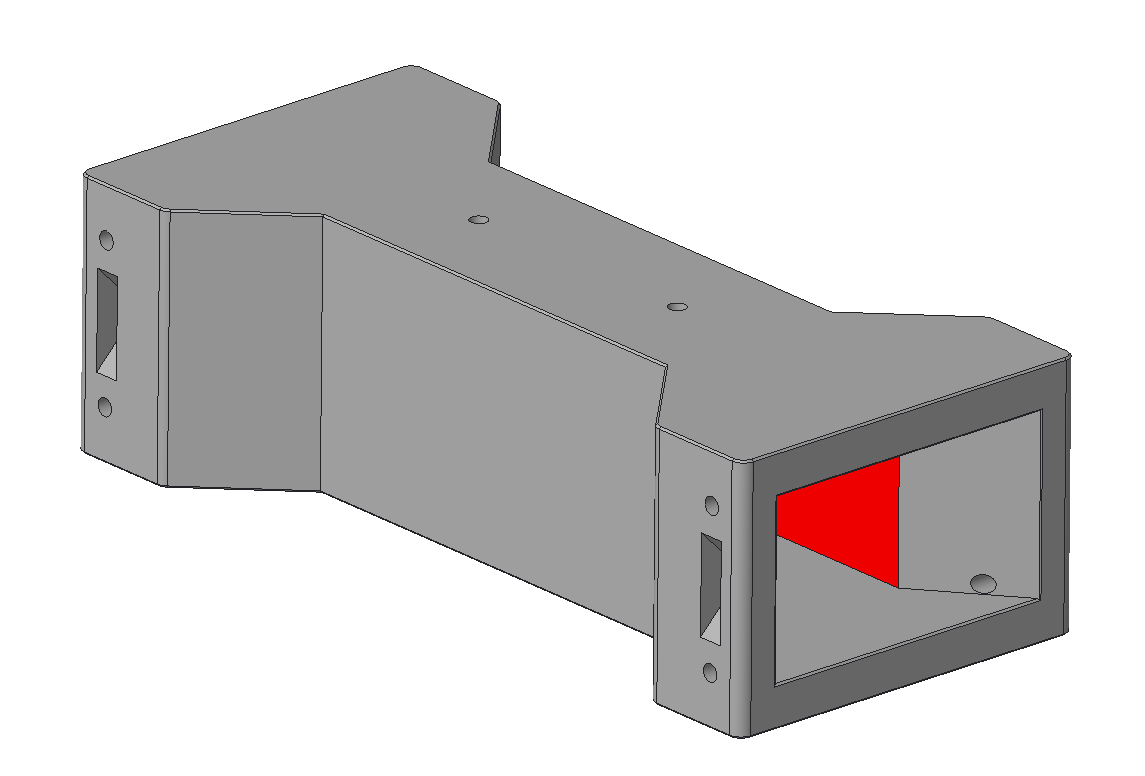
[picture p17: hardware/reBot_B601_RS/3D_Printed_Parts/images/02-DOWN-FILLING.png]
| Upper Arm Center Filler |  | 01_Upper_Arm_Fuller_M.step | Bambu ABS Black | 1 | 0.4 nozzle, 0.2 layer height, 30% infill |
| Upper Arm Horizontal Limit Block |  | 01_Upper_Arm_Limit.step | Bambu ABS Black | 1 | 0.4 nozzle, 0.2 layer height, 30% infill |
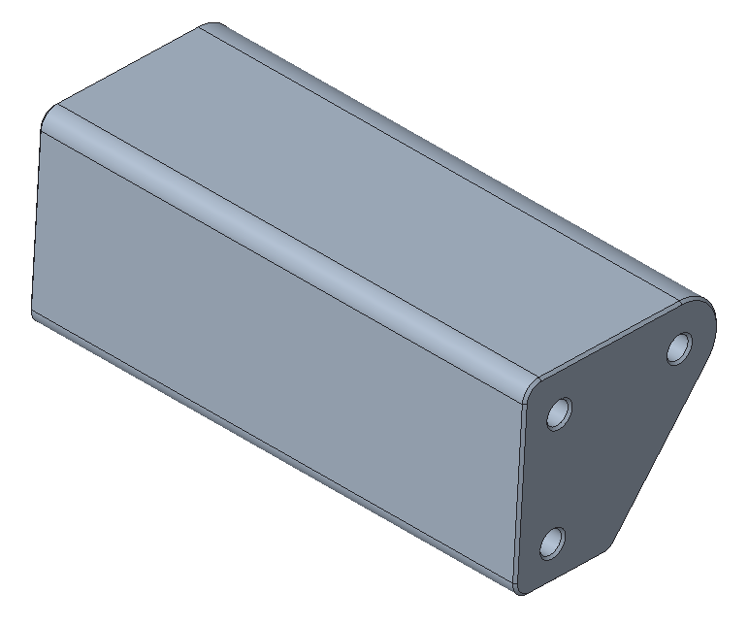
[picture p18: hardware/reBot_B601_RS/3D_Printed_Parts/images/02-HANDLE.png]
| Arm Handle |  | 01_Arm_Handle.step | Bambu ABS Black | 1 | 0.4 nozzle, 0.2 layer height, 30% infill |
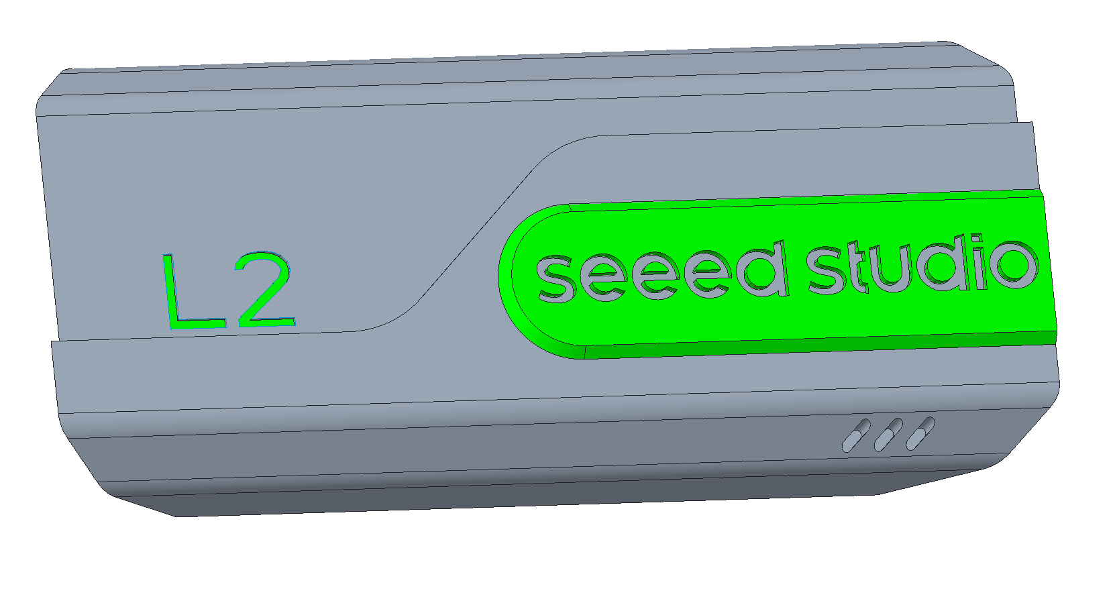
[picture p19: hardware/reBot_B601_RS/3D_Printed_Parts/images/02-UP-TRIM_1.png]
| Lower Arm Left Filler |  | 01_Lower_Arm_Filler_L.step | Bambu PLA Black & Green | 1 | 0.4 nozzle, 0.2 layer height, 15% infill |
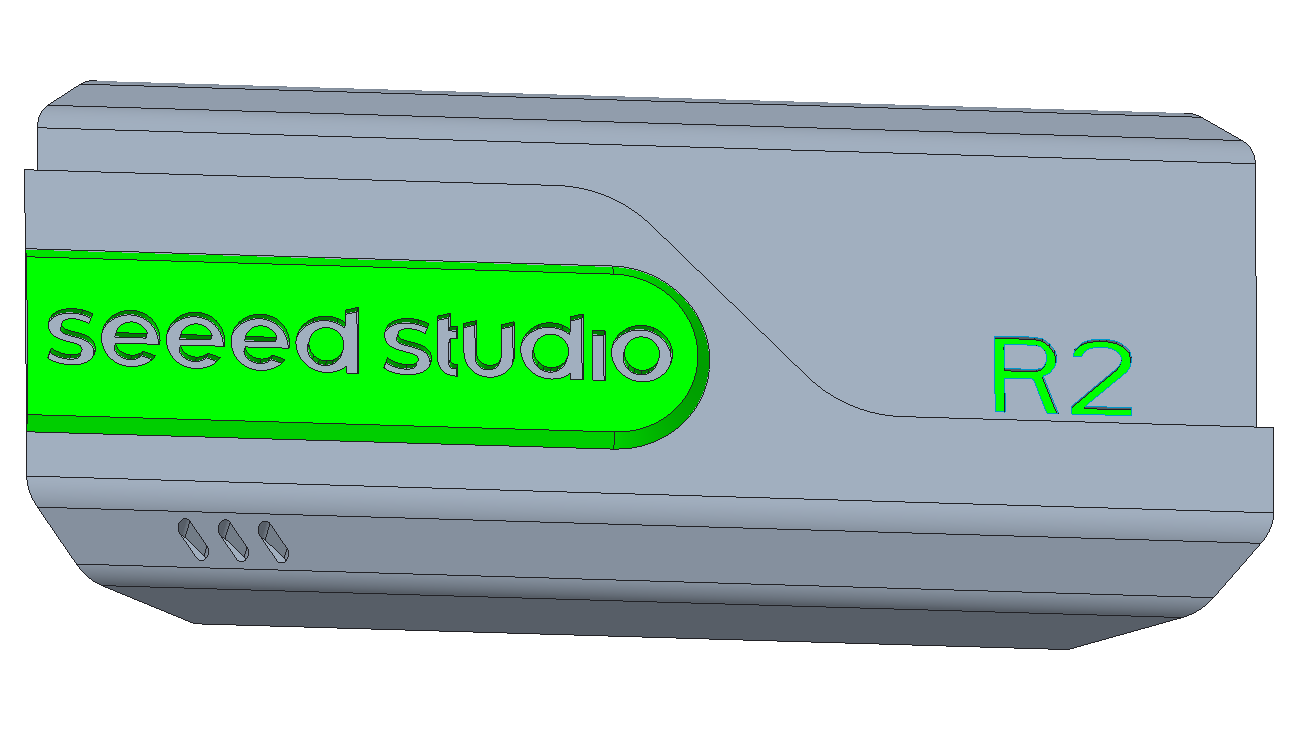
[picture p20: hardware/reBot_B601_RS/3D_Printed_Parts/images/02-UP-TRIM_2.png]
| Lower Arm Right Filler |  | 01_Lower_Arm_Filler_R.step | Bambu PLA Black & Green | 1 | 0.4 nozzle, 0.2 layer height, 15% infill |
| Lower Arm Center Filler |  | 01_Lower_Arm_Filler_M.step | Bambu ABS Black | 1 | 0.4 nozzle, 0.2 layer height, 30% infill |
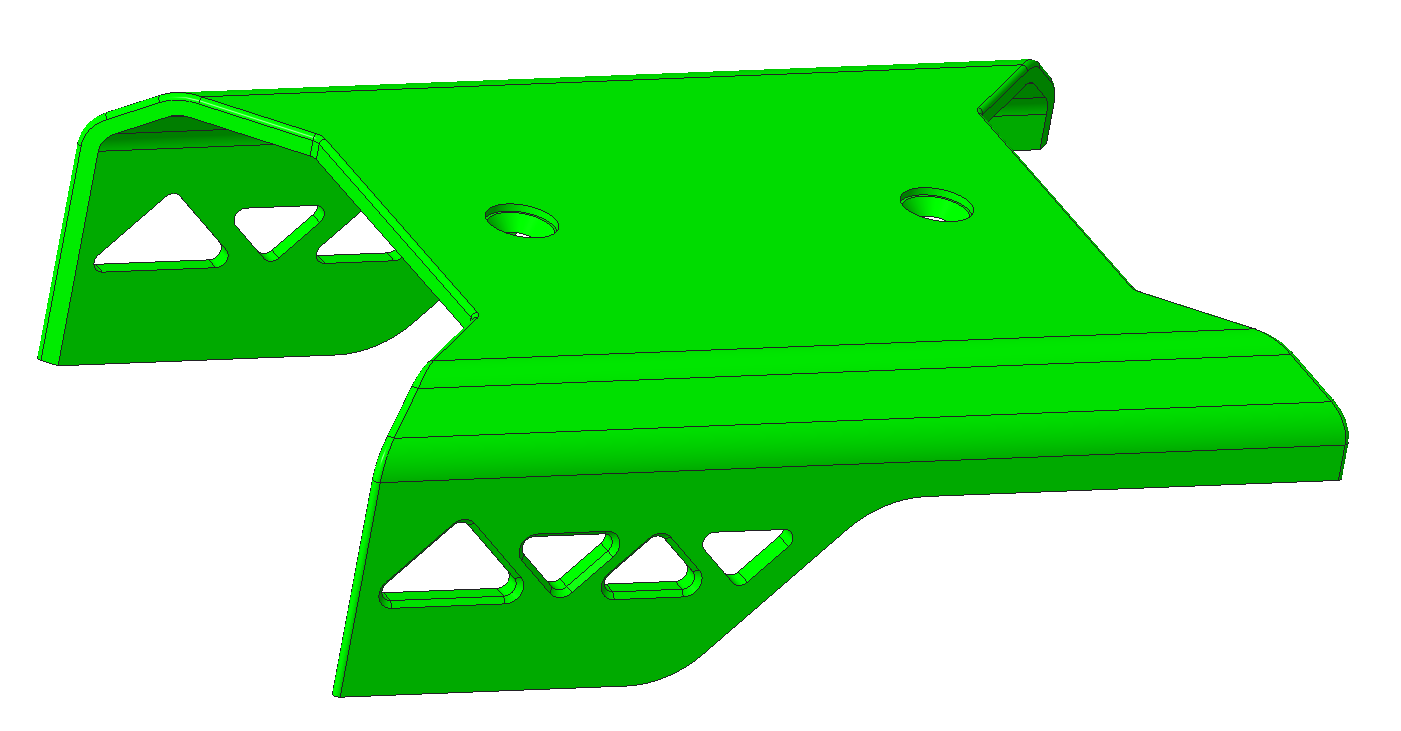
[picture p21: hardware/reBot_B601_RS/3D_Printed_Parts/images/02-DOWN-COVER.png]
| Upper Arm Cover |  | 01_Upper_Arm_Cover.step | Bambu PLA Green | 1 | 0.4 nozzle, 0.2 layer height, 15% infill |
| Lower Arm Cover |  | 01_Lower_Arm_Cover.step | Bambu PLA Green | 1 | 0.4 nozzle, 0.2 layer height, 15% infill |
| Motor 5 Protection Cover |  | 01_Motor_Cover.step | Bambu ABS Black | 1 | 0.4 nozzle, 0.2 layer height, 30% infill |
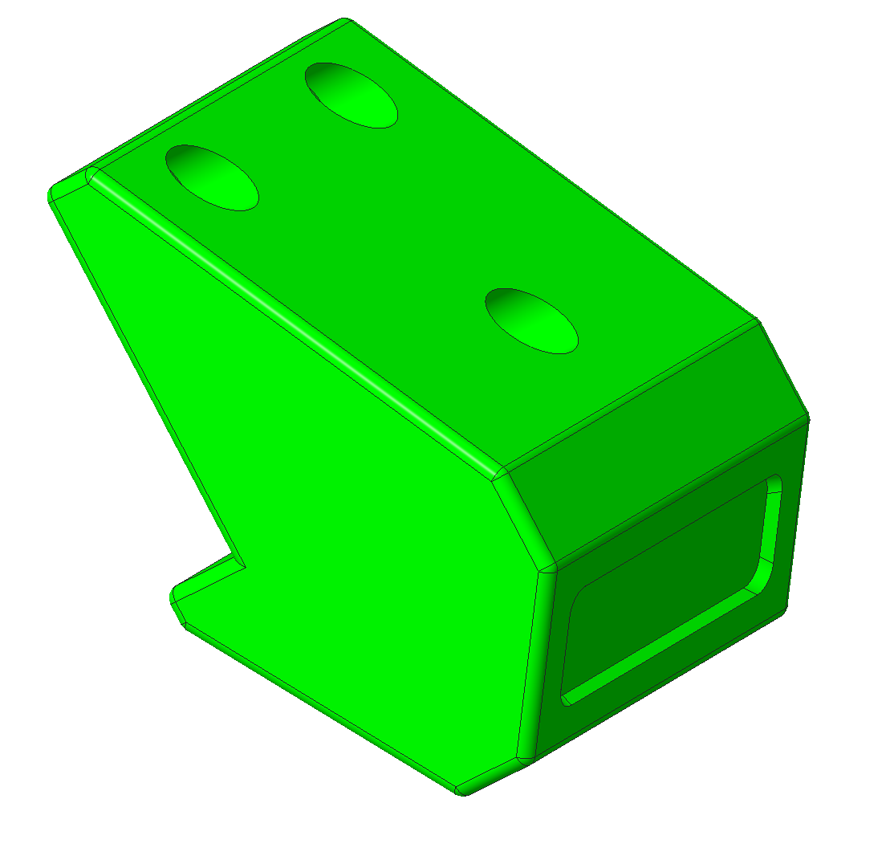
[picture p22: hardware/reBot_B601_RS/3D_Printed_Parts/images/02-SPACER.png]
| Gripper Horizontal Limit |  | 01_Lower_Arm_Limit.step | Bambu PLA Green | 1 | 0.4 nozzle, 0.2 layer height, 15% infill |
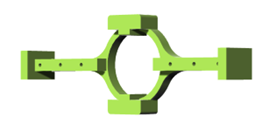
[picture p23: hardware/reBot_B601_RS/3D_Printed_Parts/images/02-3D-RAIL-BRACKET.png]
| Gripper Slider Support Bracket |  | 01-Rail-Bracket.step | Bambu PLA Green | 1 | 0.4 nozzle, 0.2 layer height, 15% infill |
| Gripper Finger |  | 01_Finger.step | Bambu ABS Black | 2 | 0.4 nozzle, 0.2 layer height, 45% infill |
| Motor 5 Cable Restraint |  | 01_Joint5_Cable Restraint_A.step | Bambu PLA Green | 1 | 0.4 nozzle, 0.2 layer height, 15% infill |
| Motor 6 & 7 Cable Restraint A |  | 01_Joint6_7_Cable Restraint_A.step | Bambu ABS Black | 2 | 0.4 nozzle, 0.2 layer height, 30% infill |
| Motor 6 & 7 Cable Restraint B |  | 01_Joint6_7_Cable Restraint_B.step | Bambu ABS Black | 2 | 0.4 nozzle, 0.2 layer height, 30% infill |
| - | Reference Price | Average **50$** | | | Price varies by material cost and printing time |

Long-term dragging of Wiring Harness 1 may abrade the motor connector and result in poor electrical contact. Printing the parts listed below can mitigate this risk.

| Part Description | Image | File Name | Material | Qty | Remarks |
| ---- | ---- | ---- | ---- | ---- | ---- |
| Wiring Harness Clips for Two Sides of Motor 1 |  | `DM_Motor1_wiring_harness_clip.stp` | Bambu Lab Black ABS | 2 | 0.4 mm nozzle, 0.2 mm layer height, 30% infill |

## 📷 Compatible Camera Mount

| Part Description | Image | File Name | Material | Qty | Notes |
|---|---|---|---|---|---|
| [Orbbec Gemini2](https://www.seeedstudio.com/Orbbec-Gemini-2-3D-Camera-p-6464.html) |  | [`D435_Gemini2_Mount.step`](./3D_Printed_Parts/D435_Gemini2_Mount.step) | Bambu ABS Black | 1 | 0.4mm Nozzle, 0.2mm Layer Height, 30% Infill |

### 🧩 Printing Recommendations
- Layer height: 0.2 mm
- Nozzle: 0.4 mm
- Supports: Add as needed
- Materials: High-temperature and load-bearing parts use ABS with 30–80% infill; may also use nylon or carbon-fiber reinforced materials. Cosmetic parts use PLA with 15% infill.
- Recommended materials for load-bearing parts:

---

## 🔩 CNC Machined Metal Parts

> [!WARNING]
> Some parts that can be replaced with 3D printing are noted in the remarks, which can significantly reduce costs.

| Part Description | Image | File Name | Material | Qty | Machining | Notes |
|---|---|---|---|---|---|---|
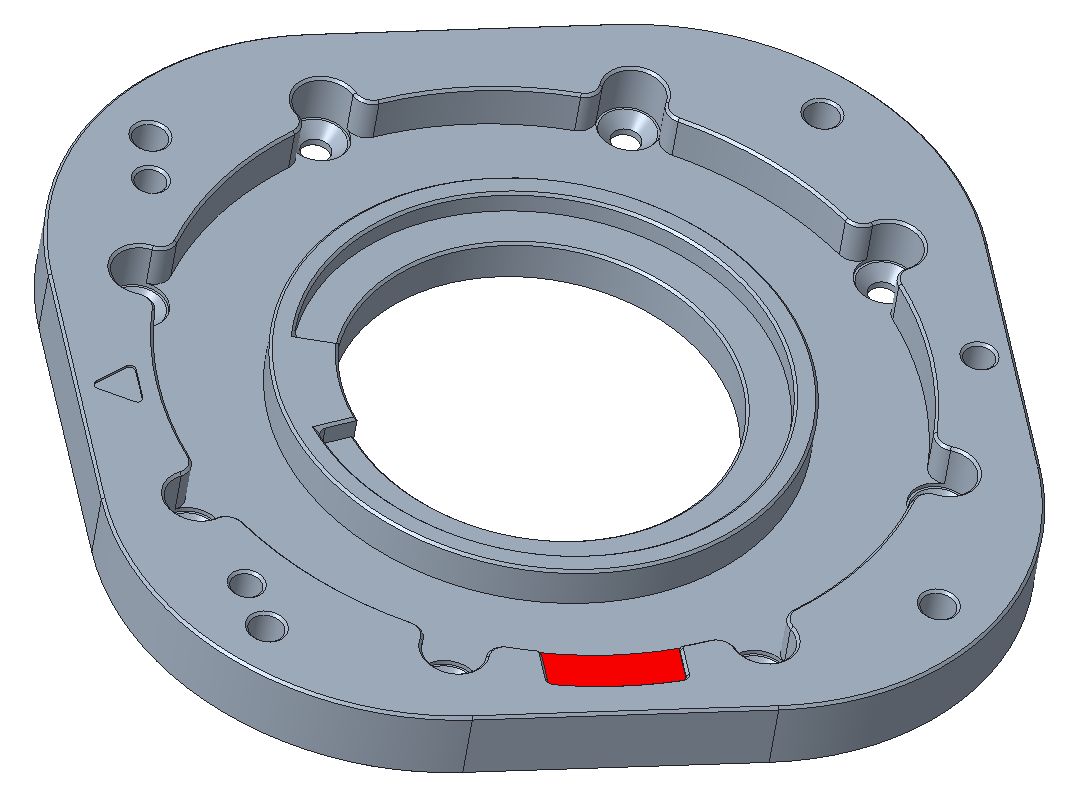
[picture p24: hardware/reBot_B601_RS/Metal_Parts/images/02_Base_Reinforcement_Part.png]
| Motor 1 Bearing Mount |  | 02_Base_Reinforcement_Part.step | Aluminum Alloy 5052 | 1 | CNC | Can be 3D printed in ABS with high infill to reduce cost |
| Motor 1 Rotation Axis |  | 02_Arm_Yaw_Limit.step | Aluminum Alloy 5052 | 1 | CNC | Added yaw angle motion limit |
| Motor 2–5 Front Spacer |  | 02_Motor_Front_Spacer.step | Aluminum Alloy 5052 | 4 | CNC | Can be 3D printed in ABS with 30% infill |
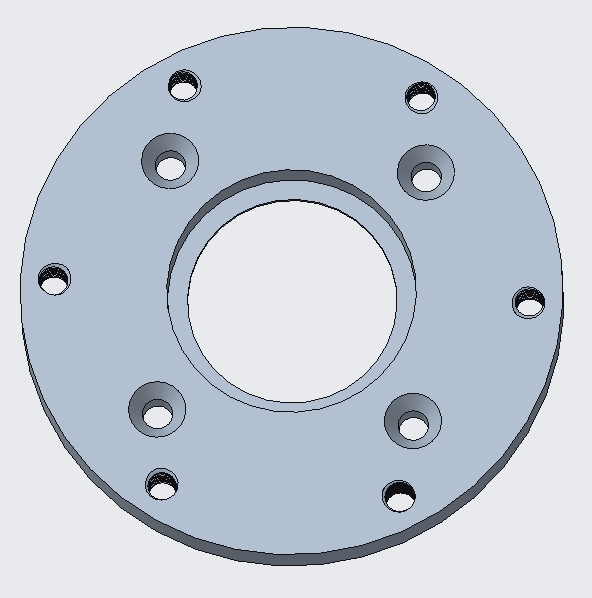
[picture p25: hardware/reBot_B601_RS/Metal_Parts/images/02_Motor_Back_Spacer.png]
| Motor 2–4 Rear Spacer |  | 02_Motor_Back_Spacer.step | Aluminum Alloy 5052 | 3 | CNC | |
| Motor 2–4 Rear Flange |  | 02_FLANGE.step | Aluminum Alloy 5052 | 3 | CNC | |
| Wrist Motor 5 Bracket |  | 02_Wrist_Bracket.step | Aluminum Alloy 5052 | 1 | CNC | |
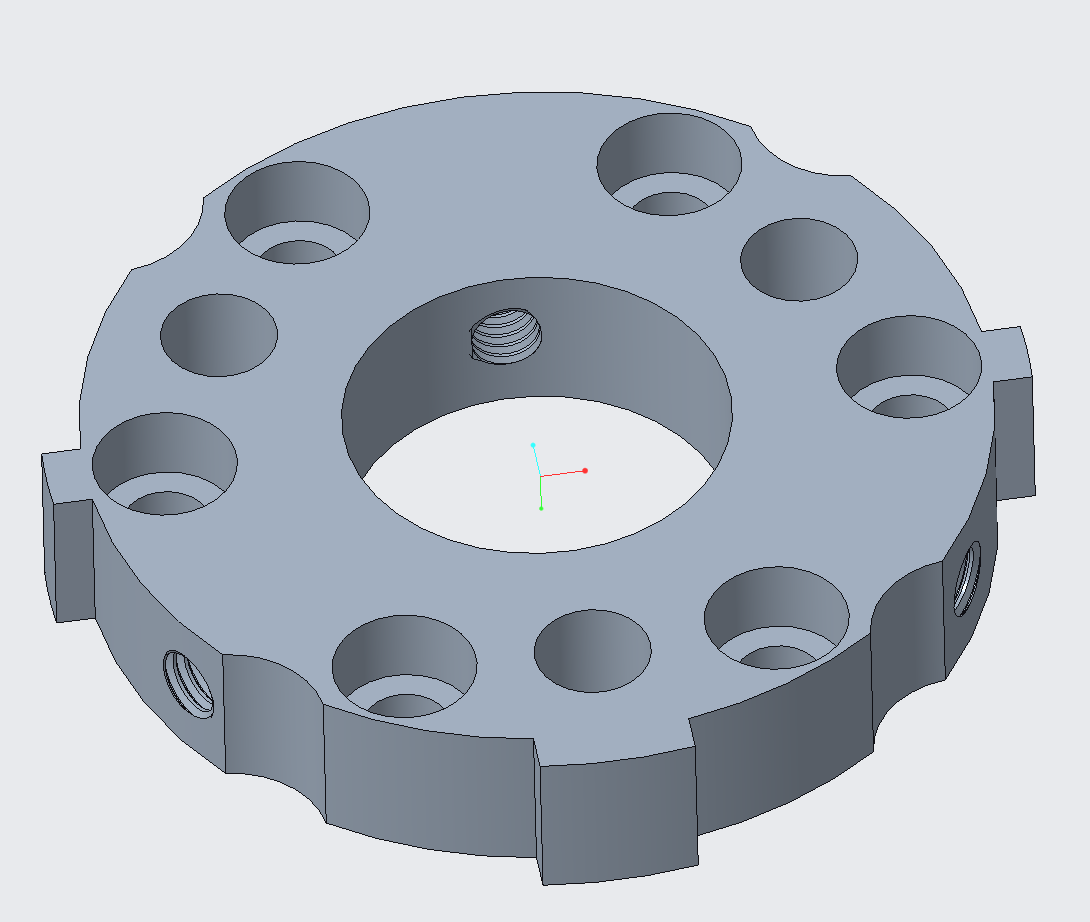
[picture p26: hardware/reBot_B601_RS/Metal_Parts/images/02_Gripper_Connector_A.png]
| Gripper Connector A |  | 02_Gripper_Connector_A.step | Aluminum Alloy 5052 | 1 | CNC | |
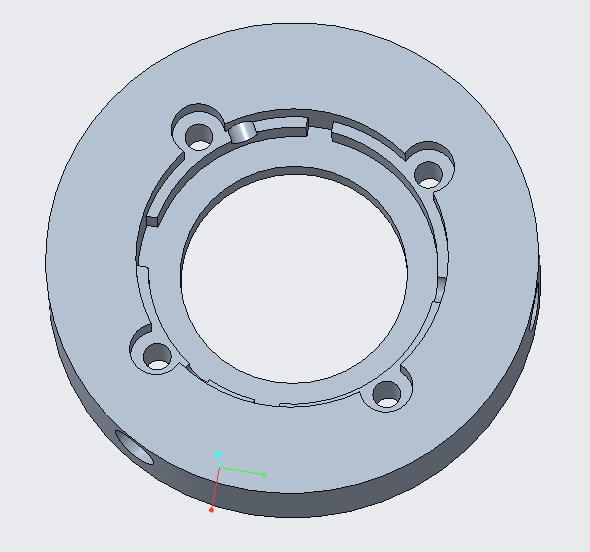
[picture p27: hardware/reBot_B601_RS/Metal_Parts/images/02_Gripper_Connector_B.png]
| Gripper Connector B |  | 02_Gripper_Connector_B.step | Aluminum Alloy 5052 | 1 | CNC | |
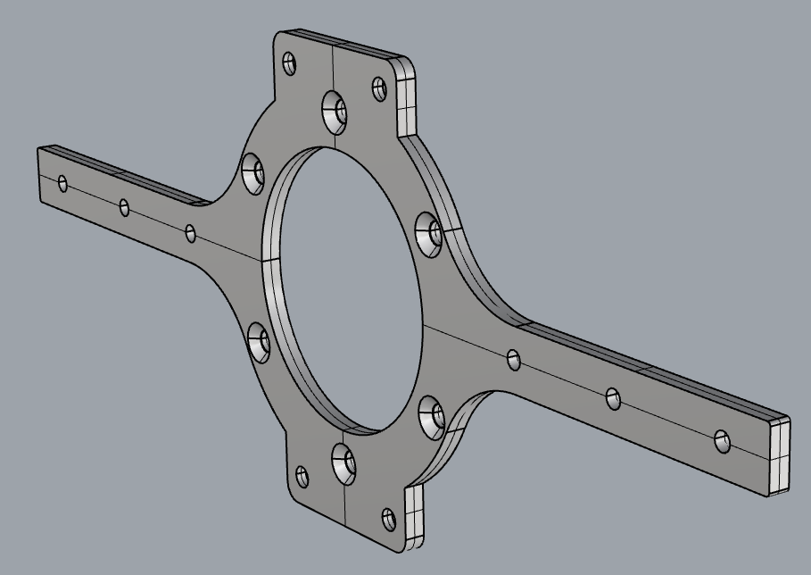
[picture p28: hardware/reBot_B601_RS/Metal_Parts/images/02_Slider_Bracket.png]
| Gripper Slider Metal Bracket |  | 02_Slider_Bracket.step | Aluminum Alloy 5052 | 1 | CNC | Can be 3D printed in ABS with high infill, not recommended for long-term use |
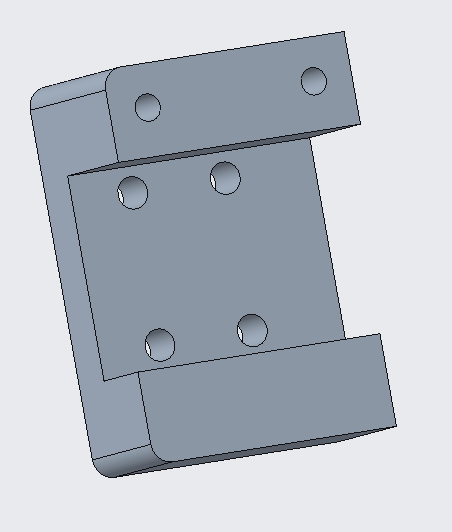
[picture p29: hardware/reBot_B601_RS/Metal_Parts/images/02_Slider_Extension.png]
| Slider to Gripper Extension |  | 02_Slider_Extension.step | Aluminum Alloy 5052 | 2 | CNC | |
| Upper-Lower Arm Link Left |  | 02_Lower_Upper_Link_L.step | Aluminum Alloy 5052 | 1 | CNC | |
| Upper-Lower Arm Link Right |  | 02_Lower_Upper_Link_R.step | Aluminum Alloy 5052 | 1 | CNC | |
| Lower Arm-Wrist Link Left |  | 02_Lower_Wrist_Link_L.step | Aluminum Alloy 5052 | 1 | CNC | |
| Lower Arm-Wrist Link Right |  | 02_Lower_Wrist_Link_R.step | Aluminum Alloy 5052 | 1 | CNC | |
| Gear Connector |  | 02_Gear_Connector.step | Aluminum Alloy 5052 | 1 | CNC | |
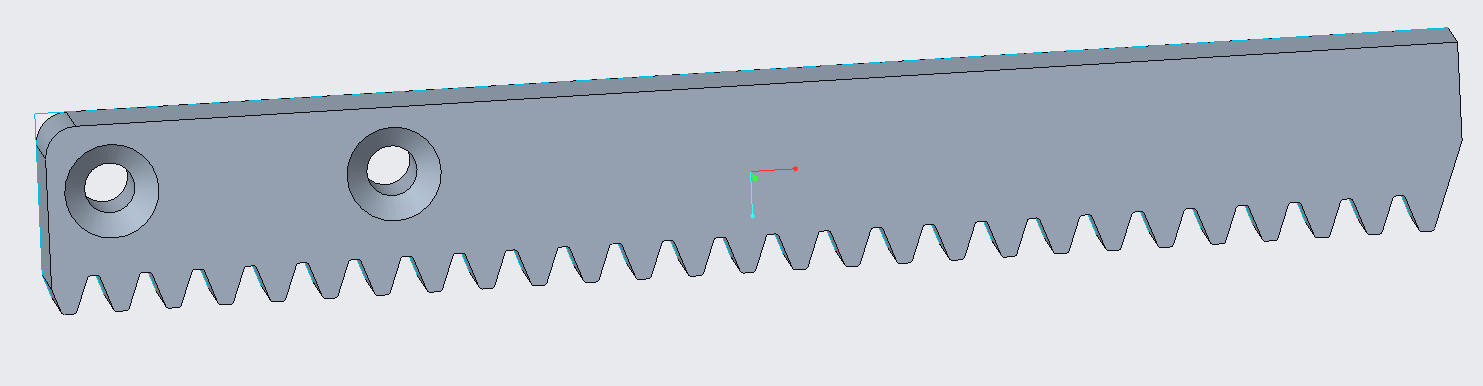
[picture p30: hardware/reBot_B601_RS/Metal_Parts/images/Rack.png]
| Rack |  | 02_Rack.step | Aluminum Alloy 5052 | 2 | CNC | |
| Link 1 |  | 03_Link1.step | Aluminum Alloy 5052 | 1 | CNC + Sheet Metal | |
| Link 2 |  | 03_Link2.step | Aluminum Alloy 5052 | 2 | CNC + Sheet Metal | |
| Link 3 Left |  | 03_Link3_L.step | Aluminum Alloy 5052 | 1 | CNC + Sheet Metal | |
| Link 3 Right |  | 03_Link3_R.step | Aluminum Alloy 5052 | 1 | CNC + Sheet Metal | |
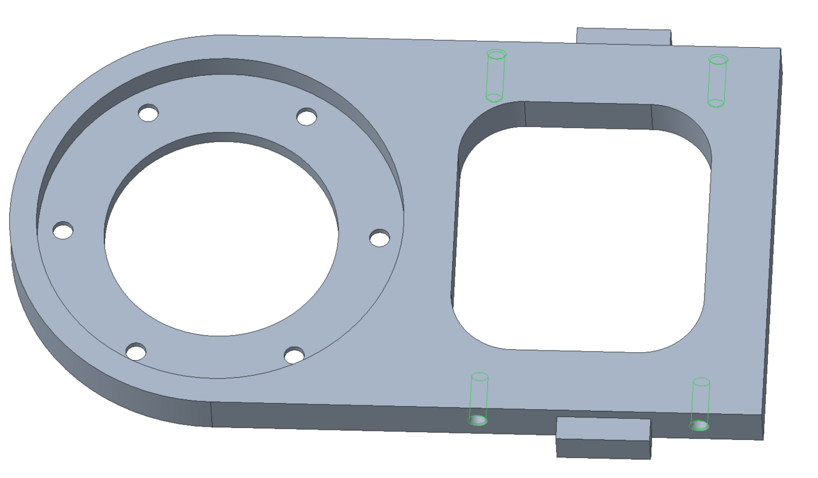
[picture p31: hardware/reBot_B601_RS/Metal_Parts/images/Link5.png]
| Link 5 |  | 03_Link5.step | Aluminum Alloy 5052 | 1 | CNC + Sheet Metal | |
| - | Market Reference Price | Average **250$** | | | Price varies by aluminum cost, tolerance requirements, lead time |

### 🧩 Machining Specifications
- Key dimension tolerance: ±0.02 mm GB/T1840-M
- Surface finish: Anodizing / Sandblasting
- Mating parts recommended: H7 / interference fit
---

## 🛒 Purchased Parts (Standard Parts)

> [!WARNING]
> Since everyone will need to assemble and tighten the screws themselves, standard hex socket screws have been selected. After prolonged operation, the screws may loosen, which will affect the precision of the robotic arm. For this reason, you are required to purchase additional hot melt glue to perform thread locking on the screws at each joint.

If you have a power drill or similar tools, you may choose to buy lock washers or thread-locking screws instead. However, **it is extremely important** that you use the lowest torque setting when using an electric screwdriver to avoid thread stripping, which will result in irreversible damage.

  | Name | Specification / Model | Quantity | Reference Price | Notes |
  |------|----------|------|----------|------|
  | Brushless motor | DM4310(V4) | 4 | 120 $/unit | [SeeedStudio](https://www.seeedstudio.com/Damiao-4310-Actuator-Motor-p-6823.html) |
  | Brushless motor | DM4340P(V4) | 3 | 175 $/unit |  [SeeedStudio](https://www.seeedstudio.com/DM4340P-Actuator-p-6663.html)  |
  | CAN-USB driver board |  | 1 | 15 $/unit |   [SeeedStudio](https://www.seeedstudio.com/DM-CAN-USB-Driver-Borad-p-6706.html)   |
  | Bearing | 6707ZZ | 1 | 13 $/unit | [Amazong](https://www.amazon.com/uxcell-35x44x5mm-Shielded-Precision-Lubricated/dp/B0D6WBMW3F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) |
  | Bearing | 6803ZZ | 3 | 13 $/unit | [Amazong](https://www.amazon.com/uxcell-17x26x5mm-Shielded-Precision-Lubricated/dp/B0D54JSWBZ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) |
  | Bearing | AXK5578 | 1 | 12 $/unit | [Amazong](https://www.amazon.com/PZRT-AXK5578-Thrust-Bearings-Washers/dp/B0B3M3RZGW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) |
  | Linear rail | MGN9-170mm | 1 | 23 $/unit | [Amazong](https://www.amazon.com/uxcell-Sliding-Carriage-Bearing-Printers/dp/B0D54L45WM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) |
  | Slider block | MGN9 | 2 | 10 $/unit | [Amazong](https://www.amazon.com/uxcell-Bearing-Sliding-Carriage-Anti-Fall/dp/B0D9QBQDKB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) |
  | Gear | Module 1, boss type, 16 teeth, 6 mm bore | 1 | 44$/unit | [Amazong](https://www.amazon.com/Module-15-Teeth-Finished-Perforation/dp/B0GDSR1LKM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)  |
  | Silicone pad | 30x9x2mm | 1 | 10 $ | [Amazong](https://www.amazon.com/Self-Adhesive-Anti-Sliding-Anti-Scratch-Protectors-Appliances/dp/B0F9KVYXFZ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) |
  | Screw | HM3-12mm screw | 14+ |  | [Amazong](https://www.amazon.com/BNUOK-120pcs-Stainless-Threads-Spanner/dp/B0DJQGMQZM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) |
  | Screw | HM3-25mm screw | 14+ |  | [Amazong](https://www.amazon.com/BNUOK-120pcs-Stainless-Threads-Spanner/dp/B0DJQFGRPQ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)  |
  | Screw | HM3-6mm screw | 16+ |  | [Amazong](https://www.amazon.com/BNUOK-120pcs-Stainless-Threads-Spanner/dp/B0DJQG5YLF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)  |
  | Screw | HM4-75mm set screw | 4+ |  | [Amazong](https://www.amazon.com/iexcell-Partially-Threaded-Thread-Socket/dp/B0DR1NX178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)  |
  | Screw | KM3*12mm screw | 30+ |  |  [Amazong](https://www.amazon.com/Uxcell-a16011300ux0872-M3x12mm-Carbon-Countersunk/dp/B01E6EIC2S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) |
  | Screw | KM3*16mm screw | 34+ |  | [Amazong](https://www.amazon.com/Uxcell-a16011300ux0872-M3x12mm-Carbon-Countersunk/dp/B01E6EIC2S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)  |
  | Screw | KM3*7mm screw | 76+ |  |[Amazong](https://www.amazon.com/Uxcell-a16011300ux0872-M3x12mm-Carbon-Countersunk/dp/B01E6EIC2S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)   |
  | Screw | KM3*9mm screw | 31+ |  |[Amazong](https://www.amazon.com/Uxcell-a16011300ux0872-M3x12mm-Carbon-Countersunk/dp/B01E6EIC2S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)   |
  | Screw | KM3*8mm Socket Micro Profile Head Screw | 31+ |  |[Amazong](https://www.amazon.com/SMALLRIG-Screw-Screws-12pcs-Pack/dp/B01MS60KSY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)   |
  | Screw | KA3*12mm | 72+ |  | [Amazong](https://www.amazon.com/uxcell-Phillips-Tapping-Screws-Silver/dp/B01MXSS95N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)  |
  | Dowel pin | M4*8mm | Several |  | [Amazong](https://www.amazon.com/HARFINGTON-Stainless-Cylindrical-Furniture-Installation/dp/B0F6CWL4MP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)  |
  | Dowel pin | M4*12mm | Several |  | [Amazong](https://www.amazon.com/HARFINGTON-Stainless-Cylindrical-Furniture-Installation/dp/B0F6CWL4MP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)  |
  | Screwdriver set | Hex key set | 1 | 16$  | [Amazong](https://www.amazon.com/Amazon-Basics-Ratcheting-Electronics-Screwdriver/dp/B07V4TFWFZ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)  |
  |  | XT30 2+2 350mm | 2 | 4 $/cable | Both ends angled |
  |  | XT30 2+2 350mm | 1 | 4 $/cable | One angled end and one straight end |
  |  | XT30 2+2 200mm | 3 | 4 $/cable | Both ends angled |
  |  | XT30 2+2 200mm | 1 | 3 $/cable | Both ends straight |

### About Fixing
You may modify your base freely based on the 3D printed parts we provide. You can also use G-clamps according to the thickness of your desktop.

  | Name | Specification / Model | Quantity | Reference Price | Notes |
  |------|----------|------|----------|------|
  | Woodworking clamp | 6-inch G clamp | 2 | 20 $/unit | [Amazong](https://www.amazon.com/gp/aw/d/B092J1YW2M/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) |

### About Power Supply
The robotic arm is shipped without a power supply by default. You may connect your own battery, or purchase a reliable 24V 14.6A MeanWell power supply made in Taiwan. Additionally, you will need to buy a three-pin plug compliant with local standards and a wiring harness with XT30 female connector.

#### Consumables BOM

| Name | Specification | Qty | Reference Price | Notes | Image |
|:---|:---|:---:|:---:|:---|:---:|
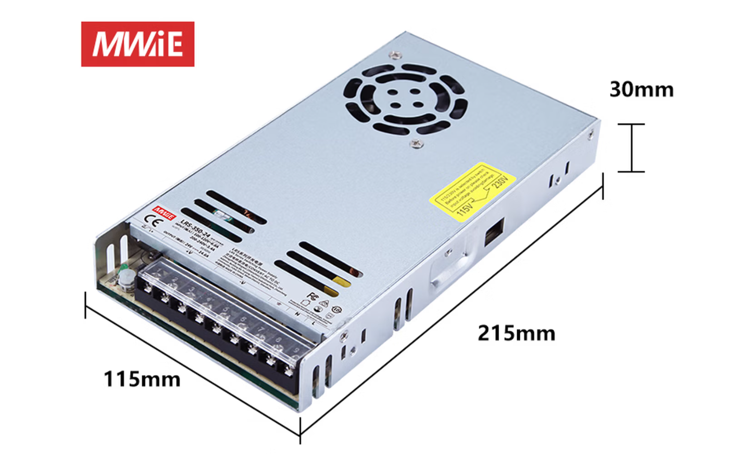
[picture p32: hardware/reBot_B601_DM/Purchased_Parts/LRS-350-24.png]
| Power Supply | LRS-350-24 (24V 14.6A) | 1 | $27.35 | [amazon](https://www.amazon.com/MEAN-WELL-LRS-350-24-350-4W-Switchable/dp/B013ETVO12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) |  |
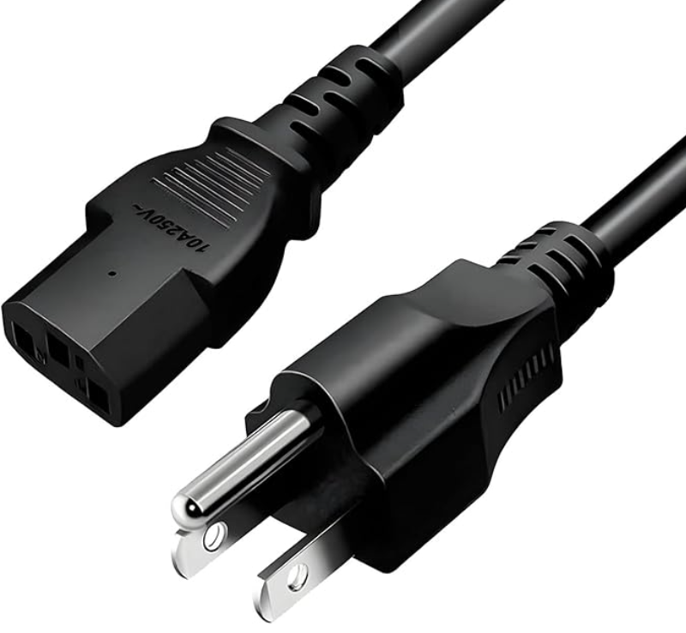
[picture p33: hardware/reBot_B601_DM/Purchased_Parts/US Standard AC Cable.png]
| Power Cord | US Standard AC Cable | 1 | $4.49 | [amazon](https://www.amazon.com/LIFEPOE-Power-3-3ft-Black-3-Prong/dp/B0FK4KPW2G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) |  |
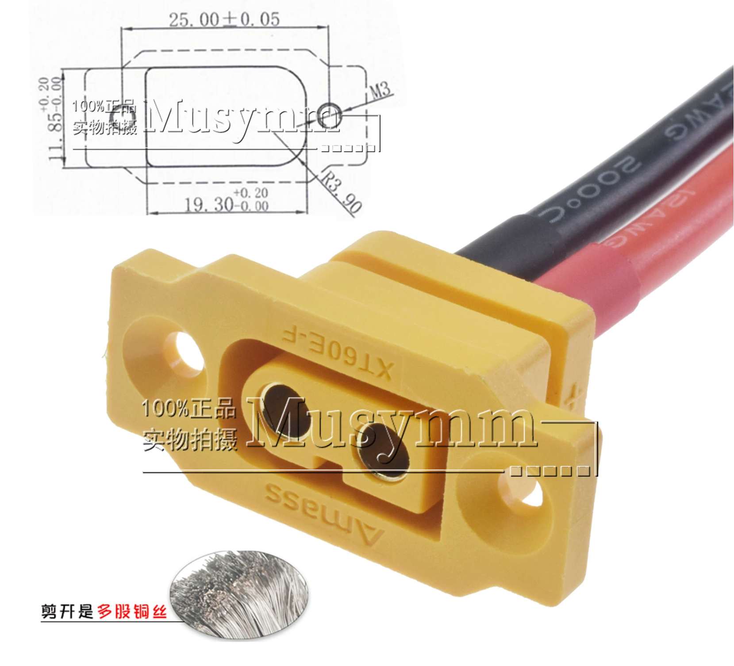
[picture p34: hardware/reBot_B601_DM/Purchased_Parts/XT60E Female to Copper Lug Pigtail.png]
| Output Port | XT60E Fixed Female Connector; XT60E Female + Lug - 10cm; 4mm Lug Hole | 1 | $9.99 | [amazon](https://www.amazon.com/LINSYRC-XT60E-F-Connector-Battery-Quadcopter/dp/B0CQK1P1DP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) |  |
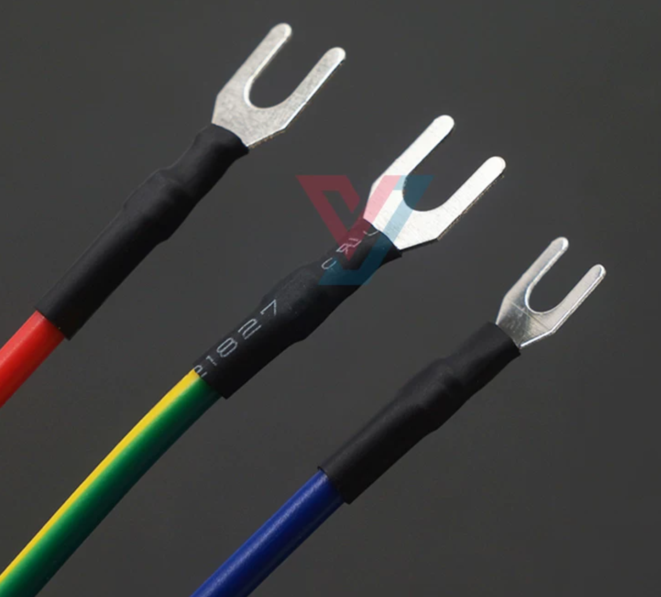
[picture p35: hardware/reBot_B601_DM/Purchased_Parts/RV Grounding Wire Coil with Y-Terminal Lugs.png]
| Power AC Wiring | 1.5mm²; Red, Blue, Yellow x1 each(User must crimp terminals to the wire — pre-crimped leads not included.); 10CM | 3 | $0.99 | [aliexpress](https://www.aliexpress.com/item/1005008648016252.html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) |  |
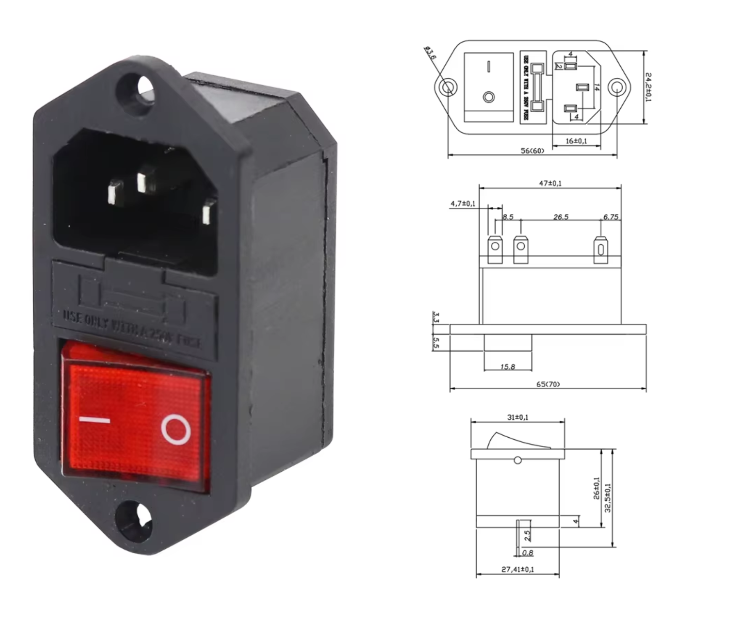
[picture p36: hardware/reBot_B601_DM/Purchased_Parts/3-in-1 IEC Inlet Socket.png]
| 3-in-1 IEC Inlet Socket | Quick-connect type with red switch (Dual Nuts) | 1 | $1.98 | [aliexpress](https://www.aliexpress.com/item/1005005962021242.html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) |  |
| XT30 to XT60 adapter cable plug | XT30U female to XT60 male | 1 | 8.99$ | [amazon](https://www.amazon.com/dp/B0BY8PSHK6?th=1) |  |
| 304 Stainless Steel Phillips Countersunk Head Screw | M4x6 | 6 | $0.37 | / | / |
| 304 Stainless Steel Phillips Countersunk Head Screw | M3x8 | 2 | $0.36 | / | / |
| 304 Stainless Steel Phillips Pan Head Screw | M3x8 | 2 | $0.32 | / | / |
| Hex Nut | M3x2.5 | 2 | 2.10 CNY | / | / |

#### Printed Parts BOM

| Name | Image | Qty | Notes |
|:---|:---|:---:|:---|
| [Front Cover](./3D_Printed_Parts/DM-power-Top%20Cover.stp) |  | 1 | PLA, 0.4mm Nozzle, 0.2mm Layer Height, 30% Infill |
| [Rear Cover](./3D_Printed_Parts/DM-power-Bottom%20Cover.stp) |  | 1 | PLA, 0.4mm Nozzle, 0.2mm Layer Height, 30% Infill |
| [Front Cover Slider](./3D_Printed_Parts/DM-power-Top%20Cover-Sliding%20Cover.stp) |  | 1 | PLA, 0.4mm Nozzle, 0.2mm Layer Height, 30% Infill |

#### Power Supply Assembly

The power supply assembly is divided into two main sections: the Front Cover and the Rear Cover.

##### 1. Front Cover Assembly

| Step | Operation Instructions | Image | Remarks |
|:---:|---|---|---|
| 1-1 | Prepare the parts and printed components required for front shell assembly |  | Check that all parts are complete |
| 1-2 | Wiring sequence instructions for each part; assemble according to the wiring sequence | <br> | Connect strictly according to the wiring sequence |
| 1-3 | Install the XT60 connector |  | Secure with 304 stainless steel Phillips countersunk head screws M3x8 and hex nuts M3x2.5 |
| 1-4 | Install the 3-in-1 IEC socket |  | Secure the 3-in-1 IEC socket with 304 stainless steel Phillips pan head screws M3x8 |
| 1-5 | Internal wiring of the front shell | <br> | Check connections against the wiring sequence diagram |
| 1-6 | Secure both sides of the front shell and the power supply |  | M4x6 304 stainless steel Phillips countersunk head screws x2 |
| 1-7 | Install the sliding cover |  | Push in from the bottom of the power supply |
| 1-8 | Secure the sliding cover |  | M4x6 304 stainless steel Phillips countersunk head screws x2 |

---

##### 2. Rear Shell Assembly

| Step | Operation Instructions | Image | Remarks |
|:---:|---|---|---|
| 2-1 | Prepare the parts and printed components required for rear shell assembly |  | Check accessories for completeness |
| 2-2 | Assemble the rear shell with the power supply |  | Align the position |
| 2-3 | Secure both sides of the rear shell and the power supply |  | M4x6 304 stainless steel Phillips countersunk head screws x2 |

---

##### 3. Overall Completion

| Step | Operation Instructions | Image | Remarks |
|:---:|---|---|---|
| 1 | Power supply solution assembly completed |  | Check that all screws are tightened |

---

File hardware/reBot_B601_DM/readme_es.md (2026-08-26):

# 🤖 Especificación de hardware de código abierto de reBot DevArm

<p align="center">
  Banner de reBot-DevArm
</p>
<p align="center">
  <strong>
    <a href="./readme_zh.md">简体中文</a> &nbsp;|&nbsp;
    <a href="./readme.md">English</a> &nbsp;|&nbsp;
    <a href="./readme_jp.md">日本語</a>&nbsp;|&nbsp;
    <a href="./readme_fr.md">français</a>&nbsp;|&nbsp;
    <a href="./readme_es.md">Español</a>
  </strong>
</p>

| Fecha | Versión | Nombre del archivo | Registro de cambios |
|---|---|---|---|
|  2026-03-31 | v1.0 |  reBot_B601_DM_v1.0_20260331.step  | Subida inicial |
|  2026-04-25 | v1.1 |  reBot_B601_DM_v1.1_20260425.step  | Se añaden sujeciones de cables para los 3 motores de las articulaciones del extremo, para evitar que se aflojen y se desconecten. Se corrige el modelo de la articulación 1 de 4310 a 4340P. Se añade la pieza CNC 02_Base_Reinforcement_Part.step en la parte inferior para reforzar la rigidez de la base. |

Esta BOM corresponde al brazo robótico reBot Arm B601 DM, que utiliza motores de la serie 43 de Damiao. La otra versión, el reBot Arm B601 RS, utiliza motores RobStride; [consulta su BOM aquí](../reBot_B601_RS/README.md).

# 📦 Estructura de archivos
*   3D_Printed_Parts/: archivos STEP de todas las piezas impresas en 3D.
*   Metal_Parts/: archivos STEP de todas las piezas metálicas mecanizadas por CNC.
*   Purchased_Parts/: archivos STEP de todos los componentes comprados.
*   reBot_B601_DM_v1.1_20260425.step: archivo del ensamblaje completo del brazo robótico.

# 🛒[Consigue todas las piezas](https://www.seeedstudio.com/reBot-Arm-B601-DM-Bundle.html)
- Ofrecemos cinco opciones de kit:
  - **Kit de motores del cuerpo del brazo**: incluye solo los motores y los arneses de cableado del brazo robótico.
  - **Kit estructural del cuerpo del brazo**: incluye solo los componentes estructurales mecánicos.
  - **Kit completo de la pinza (gripper)**: incluye los motores, los arneses de cableado y los componentes estructurales de la pinza.
  - **Kit completo**: incluye el conjunto completo del cuerpo del brazo robótico y la pinza.
  - **Brazo robótico premontado**: brazo robótico acabado y totalmente montado.

# 📊 Lista de materiales (BOM)

> [!WARNING]
> Aviso: la BOM publicada **no** representa la versión final que envía Seeed. Esta v1.1 de código abierto está optimizada para que los desarrolladores puedan reproducirla con el mínimo coste, con algunos detalles no esenciales simplificados.
> La versión final de producción de Seeed incluirá grabado láser en el metal para evitar errores de montaje (poka-yoke), algunas piezas impresas en 3D se sustituirán por metal para mayor durabilidad, las holguras y tolerancias de mecanizado se ajustarán a la variabilidad de fábrica (equilibrando precisión y coste) y se añadirá cableado personalizado (p. ej., protección con malla trenzada) con coste adicional. No obstante, la estructura mecánica es idéntica.

---

## 🖨️ Piezas impresas en 3D

| Descripción de la pieza | Imagen | Nombre del archivo | Material | Cant. | Notas |
|---|---|---|---|---|---|
| Plataforma base del brazo robótico |  | 01_BASE_Plate.step | ABS Bambu Lab negro | 1 | boquilla de 0.4 mm, altura de capa de 0.2 mm, relleno del 30% |
| Eslabón de la base del brazo robótico |  | 01_BASE_Link.step | ABS Bambu Lab negro | 1 | boquilla de 0.4 mm, altura de capa de 0.2 mm, relleno del 30% |
| Relleno izquierdo del brazo superior |  | 01_Upper_Arm_Fuller_L.step | PLA Bambu Lab negro y verde | 1 | boquilla de 0.4 mm, altura de capa de 0.2 mm, relleno del 15% |
| Relleno derecho del brazo superior |  | 01_Upper_Arm_Fuller_R.step | PLA Bambu Lab negro y verde | 1 | boquilla de 0.4 mm, altura de capa de 0.2 mm, relleno del 15% |
| Relleno central del brazo superior |  | 01_Upper_Arm_Fuller_M.step | ABS Bambu Lab negro | 1 | boquilla de 0.4 mm, altura de capa de 0.2 mm, relleno del 30% |
| Tope horizontal del brazo superior |  | 01_Upper_Arm_Limit.step | ABS Bambu Lab negro | 1 | boquilla de 0.4 mm, altura de capa de 0.2 mm, relleno del 30% |
| Asa del brazo |  | 01_Arm_Handle.step | ABS Bambu Lab negro | 1 | boquilla de 0.4 mm, altura de capa de 0.2 mm, relleno del 30% |
| Relleno izquierdo del brazo inferior |  | 01_Lower_Arm_Filler_L.step | PLA Bambu Lab negro y verde | 1 | boquilla de 0.4 mm, altura de capa de 0.2 mm, relleno del 15% |
| Relleno derecho del brazo inferior |  | 01_Lower_Arm_Filler_R.step | PLA Bambu Lab negro y verde | 1 | boquilla de 0.4 mm, altura de capa de 0.2 mm, relleno del 15% |
| Relleno central del brazo inferior |  | 01_Lower_Arm_Filler_M.step | ABS Bambu Lab negro | 1 | boquilla de 0.4 mm, altura de capa de 0.2 mm, relleno del 30% |
| Cubierta del brazo superior |  | 01_Upper_Arm_Cover.step | PLA Bambu Lab verde | 1 | boquilla de 0.4 mm, altura de capa de 0.2 mm, relleno del 15% |
| Cubierta del brazo inferior |  | 01_Lower_Arm_Cover.step | PLA Bambu Lab verde | 1 | boquilla de 0.4 mm, altura de capa de 0.2 mm, relleno del 15% |
| Cubierta de protección del motor 5 |  | 01_Motor_Cover.step | ABS Bambu Lab negro | 1 | boquilla de 0.4 mm, altura de capa de 0.2 mm, relleno del 30% |
| Tope horizontal de la pinza |  | 01_Lower_Arm_Limit.step | PLA Bambu Lab verde | 1 | boquilla de 0.4 mm, altura de capa de 0.2 mm, relleno del 15% |
| Soporte del carro de la pinza |  | 01-Rail-Bracket.step | PLA Bambu Lab verde | 1 | boquilla de 0.4 mm, altura de capa de 0.2 mm, relleno del 15% |
| Dedo de la pinza |  | 01_Finger.step | ABS Bambu Lab negro | 2 | boquilla de 0.4 mm, altura de capa de 0.2 mm, relleno del 45% |
| Sujeción de cables del motor 5 |  | 01_Joint5_Cable Restraint_A.step | PLA Bambu Lab verde | 1 | boquilla de 0.4 mm, altura de capa de 0.2 mm, relleno del 15% |
| Sujeción de cables A de los motores 6 y 7 |  | 01_Joint6_7_Cable Restraint_A.step | ABS Bambu Lab negro | 2 | boquilla de 0.4 mm, altura de capa de 0.2 mm, relleno del 30% |
| Sujeción de cables B de los motores 6 y 7 |  | 01_Joint6_7_Cable Restraint_B.step | ABS Bambu Lab negro | 2 | boquilla de 0.4 mm, altura de capa de 0.2 mm, relleno del 30% |
| - | Precio de referencia | Promedio **50 $** | | | El precio varía según el coste del material y el tiempo de impresión |

El roce continuado del arnés de cableado del motor 1 puede desgastar el conector del motor y provocar un mal contacto eléctrico. Imprimir las piezas que se indican a continuación puede mitigar este riesgo.

| Descripción de la pieza | Imagen | Nombre del archivo | Material | Cant. | Notas |
| ---- | ---- | ---- | ---- | ---- | ---- |
| Clips de arnés de cableado para ambos lados del motor 1 |  | `DM_Motor1_wiring_harness_clip.stp` | ABS Bambu Lab negro | 2 | boquilla de 0.4 mm, altura de capa de 0.2 mm, relleno del 30% |

## 📷 Soporte de cámara compatible

| Descripción de la pieza | Imagen | Nombre de archivo | Material | Cant. | Notas |
|---|---|---|---|---|---|
| [Orbbec Gemini2](https://www.seeedstudio.com/Orbbec-Gemini-2-3D-Camera-p-6464.html) |  | [`D435_Gemini2_Mount.step`](./3D_Printed_Parts/D435_Gemini2_Mount.step) | Bambu ABS Negro | 1 | Boquilla 0.4 mm, altura de capa 0.2 mm, relleno 30 % |

### 🧩 Recomendaciones de impresión
- Altura de capa: 0.2 mm
- Boquilla: 0.4 mm
- Soportes: añadir según sea necesario
- Materiales: las piezas sometidas a altas temperaturas y a carga se imprimen en ABS con un relleno del 30–80%; también pueden usarse nailon o materiales reforzados con fibra de carbono. Las piezas estéticas se imprimen en PLA con un relleno del 15%.
- Materiales recomendados para las piezas portantes: ABS con relleno del 30–80%, nailon o materiales reforzados con fibra de carbono

---

## 🔩 Piezas metálicas mecanizadas por CNC

> [!WARNING]
> Algunas piezas que pueden sustituirse por impresión 3D se indican en las notas, lo que puede reducir los costes considerablemente.

| Descripción de la pieza | Imagen | Nombre del archivo | Material | Cant. | Mecanizado | Notas |
|---|---|---|---|---|---|---|
| Soporte del rodamiento del motor 1 |  | 02_Base_Reinforcement_Part.step | Aleación de aluminio 5052 | 1 | CNC | Puede imprimirse en 3D en ABS con relleno alto para reducir el coste |
| Eje de rotación del motor 1 |  | 02_Arm_Yaw_Limit.step | Aleación de aluminio 5052 | 1 | CNC | Añade un límite de movimiento del ángulo de guiñada |
| Espaciador delantero de los motores 2–5 |  | 02_Motor_Front_Spacer.step | Aleación de aluminio 5052 | 4 | CNC | Puede imprimirse en 3D en ABS con relleno del 30% |
| Espaciador trasero de los motores 2–4 |  | 02_Motor_Back_Spacer.step | Aleación de aluminio 5052 | 3 | CNC | |
| Brida trasera de los motores 2–4 |  | 02_FLANGE.step | Aleación de aluminio 5052 | 3 | CNC | |
| Soporte del motor 5 de la muñeca |  | 02_Wrist_Bracket.step | Aleación de aluminio 5052 | 1 | CNC | |
| Conector A de la pinza |  | 02_Gripper_Connector_A.step | Aleación de aluminio 5052 | 1 | CNC | |
| Conector B de la pinza |  | 02_Gripper_Connector_B.step | Aleación de aluminio 5052 | 1 | CNC | |
| Soporte metálico del carro de la pinza |  | 02_Slider_Bracket.step | Aleación de aluminio 5052 | 1 | CNC | Puede imprimirse en 3D en ABS con relleno alto; no recomendado para uso prolongado |
| Extensión del carro a la pinza |  | 02_Slider_Extension.step | Aleación de aluminio 5052 | 2 | CNC | |
| Eslabón izquierdo entre brazo superior e inferior |  | 02_Lower_Upper_Link_L.step | Aleación de aluminio 5052 | 1 | CNC | |
| Eslabón derecho entre brazo superior e inferior |  | 02_Lower_Upper_Link_R.step | Aleación de aluminio 5052 | 1 | CNC | |
| Eslabón izquierdo entre brazo inferior y muñeca |  | 02_Lower_Wrist_Link_L.step | Aleación de aluminio 5052 | 1 | CNC | |
| Eslabón derecho entre brazo inferior y muñeca |  | 02_Lower_Wrist_Link_R.step | Aleación de aluminio 5052 | 1 | CNC | |
| Conector del engranaje |  | 02_Gear_Connector.step | Aleación de aluminio 5052 | 1 | CNC | |
| Cremallera |  | 02_Rack.step | Aleación de aluminio 5052 | 2 | CNC | |
| Eslabón 1 |  | 03_Link1.step | Aleación de aluminio 5052 | 1 | CNC + chapa metálica | |
| Eslabón 2 |  | 03_Link2.step | Aleación de aluminio 5052 | 2 | CNC + chapa metálica | |
| Eslabón 3 izquierdo |  | 03_Link3_L.step | Aleación de aluminio 5052 | 1 | CNC + chapa metálica | |
| Eslabón 3 derecho |  | 03_Link3_R.step | Aleación de aluminio 5052 | 1 | CNC + chapa metálica | |
| Eslabón 5 |  | 03_Link5.step | Aleación de aluminio 5052 | 1 | CNC + chapa metálica | |
| - | Precio de referencia de mercado | Promedio **250 $** | | | El precio varía según el coste del aluminio, los requisitos de tolerancia y el plazo de entrega |

### 🧩 Especificaciones de mecanizado
- Tolerancia de las cotas clave: ±0.02 mm GB/T1840-M
- Acabado superficial: anodizado / arenado
- Se recomienda usar H7 / ajuste por interferencia en las piezas de acoplamiento
---

## 🛒 Piezas compradas (piezas estándar)

> [!WARNING]
> Dado que cada uno tendrá que montar y apretar los tornillos por su cuenta, se han elegido tornillos Allen estándar. Tras un funcionamiento prolongado, los tornillos pueden aflojarse, lo que afectará a la precisión del brazo robótico. Por este motivo, debes comprar adicionalmente pegamento termofusible para fijar las roscas de los tornillos de cada articulación.

Si tienes un taladro eléctrico o herramientas similares, puedes optar por comprar arandelas de bloqueo o tornillos con freno de rosca. No obstante, **es sumamente importante** que uses el ajuste de par más bajo al utilizar un atornillador eléctrico para evitar que los tornillos se pasen de rosca, lo que provocaría daños irreversibles.

  | Nombre | Especificación / Modelo | Cantidad | Precio de referencia | Notas |
  |------|----------|------|----------|------|
  | Motor sin escobillas | DM4310(V4) | 4 | 120 $/unidad | [SeeedStudio](https://www.seeedstudio.com/Damiao-4310-Actuator-Motor-p-6823.html) |
  | Motor sin escobillas | DM4340P(V4) | 3 | 175 $/unidad |  [SeeedStudio](https://www.seeedstudio.com/DM4340P-Actuator-p-6663.html)  |
  | Placa driver CAN-USB |  | 1 | 15 $/unidad |   [SeeedStudio](https://www.seeedstudio.com/DM-CAN-USB-Driver-Borad-p-6706.html)   |
  | Rodamiento | 6707ZZ | 1 | 13 $/unidad | [Amazon](https://www.amazon.com/uxcell-35x44x5mm-Shielded-Precision-Lubricated/dp/B0D6WBMW3F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) |
  | Rodamiento | 6803ZZ | 3 | 13 $/unidad | [Amazon](https://www.amazon.com/uxcell-17x26x5mm-Shielded-Precision-Lubricated/dp/B0D54JSWBZ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) |
  | Rodamiento | AXK5578 | 1 | 12 $/unidad | [Amazon](https://www.amazon.com/PZRT-AXK5578-Thrust-Bearings-Washers/dp/B0B3M3RZGW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) |
  | Guía lineal | MGN9-170mm | 1 | 23 $/unidad | [Amazon](https://www.amazon.com/uxcell-Sliding-Carriage-Bearing-Printers/dp/B0D54L45WM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) |
  | Carro | MGN9 | 2 | 10 $/unidad | [Amazon](https://www.amazon.com/uxcell-Bearing-Sliding-Carriage-Anti-Fall/dp/B0D9QBQDKB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) |
  | Engranaje | Módulo 1, tipo cubo, 16 dientes, agujero de 6 mm | 1 | 44 $/unidad | [Amazon](https://www.amazon.com/Module-15-Teeth-Finished-Perforation/dp/B0GDSR1LKM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)  |
  | Almohadilla de silicona | 30x9x2mm | 1 | 10 $ | [Amazon](https://www.amazon.com/Self-Adhesive-Anti-Sliding-Anti-Scratch-Protectors-Appliances/dp/B0F9KVYXFZ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) |
  | Tornillo | Tornillo HM3-12mm | 14+ |  | [Amazon](https://www.amazon.com/BNUOK-120pcs-Stainless-Threads-Spanner/dp/B0DJQGMQZM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) |
  | Tornillo | Tornillo HM3-25mm | 14+ |  | [Amazon](https://www.amazon.com/BNUOK-120pcs-Stainless-Threads-Spanner/dp/B0DJQFGRPQ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)  |
  | Tornillo | Tornillo HM3-6mm | 16+ |  | [Amazon](https://www.amazon.com/BNUOK-120pcs-Stainless-Threads-Spanner/dp/B0DJQG5YLF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)  |
  | Tornillo | Tornillo prisionero HM4-75mm | 4+ |  | [Amazon](https://www.amazon.com/iexcell-Partially-Threaded-Thread-Socket/dp/B0DR1NX178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)  |
  | Tornillo | Tornillo KM3*12mm | 30+ |  |  [Amazon](https://www.amazon.com/Uxcell-a16011300ux0872-M3x12mm-Carbon-Countersunk/dp/B01E6EIC2S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) |
  | Tornillo | Tornillo KM3*16mm | 34+ |  | [Amazon](https://www.amazon.com/Uxcell-a16011300ux0872-M3x12mm-Carbon-Countersunk/dp/B01E6EIC2S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)  |
  | Tornillo | Tornillo KM3*7mm | 76+ |  |[Amazon](https://www.amazon.com/Uxcell-a16011300ux0872-M3x12mm-Carbon-Countersunk/dp/B01E6EIC2S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)   |
  | Tornillo | Tornillo KM3*9mm | 31+ |  |[Amazon](https://www.amazon.com/Uxcell-a16011300ux0872-M3x12mm-Carbon-Countersunk/dp/B01E6EIC2S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)   |
  | Tornillo | Tornillo KM3*8mm de cabeza baja con hueco hexagonal (Socket Micro Profile Head) | 31+ |  |[Amazon](https://www.amazon.com/SMALLRIG-Screw-Screws-12pcs-Pack/dp/B01MS60KSY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)   |
  | Tornillo | KA3*12mm | 72+ |  | [Amazon](https://www.amazon.com/uxcell-Phillips-Tapping-Screws-Silver/dp/B01MXSS95N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)  |
  | Pasador cilíndrico | M4*8mm | Varios |  | [Amazon](https://www.amazon.com/HARFINGTON-Stainless-Cylindrical-Furniture-Installation/dp/B0F6CWL4MP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)  |
  | Pasador cilíndrico | M4*12mm | Varios |  | [Amazon](https://www.amazon.com/HARFINGTON-Stainless-Cylindrical-Furniture-Installation/dp/B0F6CWL4MP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)  |
  | Juego de destornilladores | Juego de llaves hexagonales | 1 | 16 $  | [Amazon](https://www.amazon.com/Amazon-Basics-Ratcheting-Electronics-Screwdriver/dp/B07V4TFWFZ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)  |
  |  | XT30 2+2 350mm | 2 | 4 $/cable | Ambos extremos en ángulo |
  |  | XT30 2+2 350mm | 1 | 4 $/cable | Un extremo en ángulo y otro recto |
  |  | XT30 2+2 200mm | 3 | 4 $/cable | Ambos extremos en ángulo |
  |  | XT30 2+2 200mm | 1 | 3 $/cable | Ambos extremos rectos |

### Sobre la fijación
Puedes modificar libremente la base a partir de las piezas impresas en 3D que proporcionamos. También puedes usar sargentos en G según el grosor de tu mesa.

  | Nombre | Especificación / Modelo | Cantidad | Precio de referencia | Notas |
  |------|----------|------|----------|------|
  | Sargento de carpintería | Sargento en G de 6 pulgadas | 2 | 20 $/unidad | [Amazon](https://www.amazon.com/gp/aw/d/B092J1YW2M/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) |

### Sobre la alimentación
El brazo robótico se envía por defecto sin fuente de alimentación. Puedes conectar tu propia batería o comprar una fuente de alimentación MeanWell fiable de 24V 14.6A fabricada en Taiwán. Además, necesitarás comprar un enchufe de tres clavijas conforme a la normativa local y un arnés de cableado con conector XT30 hembra.

#### BOM de consumibles

| Nombre | Especificación | Cant. | Precio de referencia | Notas | Imagen |
|:---|:---|:---:|:---:|:---|:---:|
| Fuente de alimentación | LRS-350-24 (24V 14.6A) | 1 | 27.35 $ | [amazon](https://www.amazon.com/MEAN-WELL-LRS-350-24-350-4W-Switchable/dp/B013ETVO12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) |  |
| Cable de alimentación | Cable de CA estándar de EE. UU. | 1 | 4.49 $ | [amazon](https://www.amazon.com/LIFEPOE-Power-3-3ft-Black-3-Prong/dp/B0FK4KPW2G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) |  |
| Puerto de salida | Conector hembra fijo XT60E; XT60E hembra + terminal de ojal - 10cm; orificio del terminal de 4mm | 1 | 9.99 $ | [amazon](https://www.amazon.com/LINSYRC-XT60E-F-Connector-Battery-Quadcopter/dp/B0CQK1P1DP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) |  |
| Cableado de CA | 1.5mm²; rojo, azul y amarillo, 1 de cada (debes crimpar tú mismo los terminales al cable; no se incluyen cables precrimpados); 10CM | 3 | 0.99 $ | [aliexpress](https://www.aliexpress.com/item/1005008648016252.html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) |  |
| Base IEC 3 en 1 | Tipo de conexión rápida con interruptor rojo (doble tuerca) | 1 | 1.98 $ | [aliexpress](https://www.aliexpress.com/item/1005005962021242.html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) |  |
| Cable adaptador XT30 a XT60 | XT30U hembra a XT60 macho | 1 | 8.99 $ | [amazon](https://www.amazon.com/dp/B0BY8PSHK6?th=1) |  |
| Tornillo avellanado Phillips de acero inoxidable 304 | M4x6 | 6 | 0.37 $ | / | / |
| Tornillo avellanado Phillips de acero inoxidable 304 | M3x8 | 2 | 0.36 $ | / | / |
| Tornillo Phillips de cabeza alomada de acero inoxidable 304 | M3x8 | 2 | 0.32 $ | / | / |
| Tuerca hexagonal | M3x2.5 | 2 | ≈0.30 $ | / | / |

#### BOM de piezas impresas

| Nombre | Imagen | Cant. | Notas |
|:---|:---|:---:|:---|
| [Carcasa frontal](./3D_Printed_Parts/DM-power-Top%20Cover.stp) |  | 1 | PLA, boquilla de 0.4 mm, altura de capa de 0.2 mm, relleno del 30% |
| [Carcasa trasera](./3D_Printed_Parts/DM-power-Bottom%20Cover.stp) |  | 1 | PLA, boquilla de 0.4 mm, altura de capa de 0.2 mm, relleno del 30% |
| [Tapa deslizante de la carcasa frontal](./3D_Printed_Parts/DM-power-Top%20Cover-Sliding%20Cover.stp) |  | 1 | PLA, boquilla de 0.4 mm, altura de capa de 0.2 mm, relleno del 30% |

#### Montaje de la fuente de alimentación

El montaje de la fuente de alimentación se divide en dos secciones principales: la carcasa frontal y la carcasa trasera.

##### 1. Montaje de la carcasa frontal

| Paso | Instrucciones | Imagen | Notas |
|:---:|---|---|---|
| 1-1 | Prepara las piezas y los componentes impresos necesarios para el montaje de la carcasa frontal |  | Comprueba que todas las piezas estén completas |
| 1-2 | Consulta las indicaciones de la secuencia de cableado de cada pieza y monta siguiéndola | <br> | Sigue estrictamente la secuencia de cableado al conectar |
| 1-3 | Instala el conector XT60 |  | Fíjalo con tornillos avellanados Phillips de acero inoxidable 304 M3x8 y tuercas hexagonales M3x2.5 |
| 1-4 | Instala la base IEC 3 en 1 |  | Fija la base IEC 3 en 1 con tornillos Phillips de cabeza alomada de acero inoxidable 304 M3x8 |
| 1-5 | Cableado interno de la carcasa frontal | <br> | Comprueba las conexiones con el diagrama de la secuencia de cableado |
| 1-6 | Fija ambos lados de la carcasa frontal y la fuente de alimentación |  | Tornillos avellanados Phillips de acero inoxidable 304 M4x6 x2 |
| 1-7 | Instala la tapa deslizante |  | Introdúcela desde la parte inferior de la fuente de alimentación |
| 1-8 | Fija la tapa deslizante |  | Tornillos avellanados Phillips de acero inoxidable 304 M4x6 x2 |

---

##### 2. Montaje de la carcasa trasera

| Paso | Instrucciones | Imagen | Notas |
|:---:|---|---|---|
| 2-1 | Prepara las piezas y los componentes impresos necesarios para el montaje de la carcasa trasera |  | Comprueba que los accesorios estén completos |
| 2-2 | Monta la carcasa trasera con la fuente de alimentación |  | Alinea la posición |
| 2-3 | Fija ambos lados de la carcasa trasera y la fuente de alimentación |  | Tornillos avellanados Phillips de acero inoxidable 304 M4x6 x2 |

---

##### 3. Finalización del conjunto

| Paso | Instrucciones | Imagen | Notas |
|:---:|---|---|---|
| 1 | Montaje del sistema de alimentación completado |  | Comprueba que todos los tornillos estén apretados |

---

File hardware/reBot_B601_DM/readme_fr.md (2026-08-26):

# 🤖 Spécifications Matérielles Open Source du reBot DevArm

<p align="center">
  reBot-DevArm Banner
</p>
<p align="center">
  <strong>
    <a href="./readme_zh.md">简体中文</a> &nbsp;|&nbsp;
    <a href="./readme.md">English</a> &nbsp;|&nbsp;
    <a href="./readme_jp.md">日本語</a>&nbsp;|&nbsp;
    <a href="./readme_fr.md">français</a>&nbsp;|&nbsp;
    <a href="./readme_es.md">Español</a>
  </strong>
</p>

| Date | Version | Nom du fichier | Historique des modifications |
|---|---|---|---|
| 2026-03-31 | v1.0 | reBot_B601_DM_v1.0_20260331.step | Mise en ligne initiale |
| 2026-04-15 | v1.1 | reBot_B601_DM_v1.1_20260415.step | Ajout de colliers de câble pour les 3 moteurs d’articulation terminale afin d’éviter le desserrage et la déconnexion. Correction du modèle de l’articulation 1 de 4310 à 4340P. Ajout de la pièce usinée CNC 02_Base_Reinforcement_Part.step à la base pour renforcer la rigidité. |

Cette nomenclature (BOM) concerne le bras robotique reBot Arm B601 DM, équipé de moteurs Damiao série 43.
L’autre version, reBot Arm B601 RS, utilise des moteurs RobStride ; [voir la nomenclature ici](../reBot_B601_RS/README.md).

# 📦 Structure des fichiers
*   3D_Printed_Parts/ : Fichiers Step de toutes les pièces imprimées en 3D.
*   Metal_Parts/ : Fichiers Step de toutes les pièces métalliques usinées CNC.
*   Purchased_Parts/ : Fichiers Step de tous les composants standard achetés.
*   reBot_B601_DM_v1.1_20260415.step : Fichier d’assemblage complet du bras robotique.

# 🛒 [Obtenir toutes les pièces](https://www.seeedstudio.com/reBot-Arm-B601-DM-Bundle.html)
- Nous proposons cinq options de kit :
  - **Kit Moteurs du Bras** : Inclut uniquement les moteurs et faisceaux de câbles du bras robotique.
  - **Kit Structure du Bras** : Inclut uniquement les composants mécaniques de structure.
  - **Kit Complet Préhenseur** : Inclut moteurs, faisceaux de câbles et composants de structure du préhenseur.
  - **Kit Complet** : Inclut l’ensemble du corps du bras robotique et du préhenseur.
  - **Bras Robotique Pré-assemblé** : Bras robotique fini entièrement assemblé.

# 📊 Nomenclature (BOM)

> [!WARNING]
> Déclaration : La nomenclature publiée **ne représente pas** la version finale livrée par Seeed.
> Cette version open source v1.1 est optimisée pour que les développeurs puissent la reproduire à coût minimal, avec certains détails non essentiels simplifiés.
> La version de production finale Seeed comprendra une gravure laser métallique pour éviter les erreurs de montage, certaines pièces imprimées en 3D seront remplacées par du métal pour plus de durabilité, les jeux et tolérances d’usinage seront ajustés pour les variations industrielles (équilibre entre précision et coût), et un câblage personnalisé (avec gaine tressée par exemple) sera ajouté avec un coût supplémentaire. Cependant, la structure mécanique reste identique.

---

## 🖨️ Pièces imprimées en 3D

| Description de la pièce | Image | Nom du fichier | Matériau | Qté | Notes |
|---|---|---|---|---|---|
| Plaque de base du bras robotique |  | 01_BASE_Plate.step | Bambu ABS Noir | 1 | Buse 0.4, hauteur de couche 0.2, remplissage 30% |
| Liaison de base du bras robotique |  | 01_BASE_Link.step | Bambu ABS Noir | 1 | Buse 0.4, hauteur de couche 0.2, remplissage 30% |
| Garniture côté gauche du bras supérieur |  | 01_Upper_Arm_Fuller_L.step | Bambu PLA Noir & Vert | 1 | Buse 0.4, hauteur de couche 0.2, remplissage 15% |
| Garniture côté droit du bras supérieur |  | 01_Upper_Arm_Fuller_R.step | Bambu PLA Noir & Vert | 1 | Buse 0.4, hauteur de couche 0.2, remplissage 15% |
| Garniture centrale du bras supérieur |  | 01_Upper_Arm_Fuller_M.step | Bambu ABS Noir | 1 | Buse 0.4, hauteur de couche 0.2, remplissage 30% |
| Butée de limite horizontale du bras supérieur |  | 01_Upper_Arm_Limit.step | Bambu ABS Noir | 1 | Buse 0.4, hauteur de couche 0.2, remplissage 30% |
| Poignée du bras |  | 01_Arm_Handle.step | Bambu ABS Noir | 1 | Buse 0.4, hauteur de couche 0.2, remplissage 30% |
| Garniture côté gauche du bras inférieur |  | 01_Lower_Arm_Filler_L.step | Bambu PLA Noir & Vert | 1 | Buse 0.4, hauteur de couche 0.2, remplissage 15% |
| Garniture côté droit du bras inférieur |  | 01_Lower_Arm_Filler_R.step | Bambu PLA Noir & Vert | 1 | Buse 0.4, hauteur de couche 0.2, remplissage 15% |
| Garniture centrale du bras inférieur |  | 01_Lower_Arm_Filler_M.step | Bambu ABS Noir | 1 | Buse 0.4, hauteur de couche 0.2, remplissage 30% |
| Cache du bras supérieur |  | 01_Upper_Arm_Cover.step | Bambu PLA Vert | 1 | Buse 0.4, hauteur de couche 0.2, remplissage 15% |
| Cache du bras inférieur |  | 01_Lower_Arm_Cover.step | Bambu PLA Vert | 1 | Buse 0.4, hauteur de couche 0.2, remplissage 15% |
| Cache de protection du moteur 5 |  | 01_Motor_Cover.step | Bambu ABS Noir | 1 | Buse 0.4, hauteur de couche 0.2, remplissage 30% |
| Butée de limite horizontale du préhenseur |  | 01_Lower_Arm_Limit.step | Bambu PLA Vert | 1 | Buse 0.4, hauteur de couche 0.2, remplissage 15% |
| Support de coulisseau du préhenseur |  | 01-Rail-Bracket.step | Bambu PLA Vert | 1 | Buse 0.4, hauteur de couche 0.2, remplissage 15% |
| Doigt de préhenseur |  | 01_Finger.step | Bambu ABS Noir | 2 | Buse 0.4, hauteur de couche 0.2, remplissage 45% |
| Collier de câble du moteur 5 |  | 01_Joint5_Cable Restraint_A.step | Bambu PLA Vert | 1 | Buse 0.4, hauteur de couche 0.2, remplissage 15% |
| Collier de câble A pour moteurs 6 & 7 |  | 01_Joint6_7_Cable Restraint_A.step | Bambu ABS Noir | 2 | Buse 0.4, hauteur de couche 0.2, remplissage 30% |
| Collier de câble B pour moteurs 6 & 7 |  | 01_Joint6_7_Cable Restraint_B.step | Bambu ABS Noir | 2 | Buse 0.4, hauteur de couche 0.2, remplissage 30% |
| - | Prix de référence | Moyenne **50$** | | | Prix variable selon coût du matériau et temps d’impression |

Lors d’une utilisation prolongée, le tirage répété du faisceau de câbles 1 provoque l’usure du connecteur du moteur et entraîne des défauts de contact. Imprimez les pièces listées ci-dessous pour limiter ce risque.

| Désignation de la pièce | Image | Nom du fichier | Matériau | Quantité | Remarques |
| ---- | ---- | ---- | ---- | ---- | ---- |
| Attache de faisceau pour les deux faces du moteur 1 |  | `DM_Motor1_wiring_harness_clip.stp` | ABS noir Bambu Lab | 2 | Buse 0,4 mm, hauteur de couche 0,2 mm, remplissage 30 % |

## 📷 Support de caméra compatible

| Description de la pièce | Image | Nom du fichier | Matériau | Qté | Notes |
|---|---|---|---|---|---|
| [Orbbec Gemini2](https://www.seeedstudio.com/Orbbec-Gemini-2-3D-Camera-p-6464.html) |  | [`D435_Gemini2_Mount.step`](./3D_Printed_Parts/D435_Gemini2_Mount.step) | Bambu ABS Noir | 1 | Buse 0.4, hauteur de couche 0.2, remplissage 30% |

### 🧩 Recommandations d’impression
- Hauteur de couche : 0.2 mm
- Buse : 0.4 mm
- Supports : Ajouter si nécessaire
- Matériaux : Pièces résistant à la chaleur et aux charges : ABS avec remplissage 30–80% ; nylon ou matériaux renforcés de fibre de carbone également possibles. Pièces esthétiques : PLA avec remplissage 15%.
- Matériaux recommandés pour les pièces sous charge :

---

## 🔩 Pièces métalliques usinées CNC

> [!WARNING]
> Certaines pièces pouvant être remplacées par impression 3D sont indiquées en note, ce qui permet de réduire significativement les coûts.

| Description de la pièce | Image | Nom du fichier | Matériau | Qté | Usinage | Notes |
|---|---|---|---|---|---|---|
| Support de palier du moteur 1 |  | 02_Base_Reinforcement_Part.step | Alliage d’aluminium 5052 | 1 | CNC | Peut être imprimé en 3D en ABS avec fort remplissage pour réduire les coûts |
| Axe de rotation du moteur 1 avec butée |  | 02_Arm_Yaw_Limit.step | Alliage d’aluminium 5052 | 1 | CNC | Ajout de limite de mouvement en lacet |
| Entretoise avant moteurs 2–5 |  | 02_Motor_Front_Spacer.step | Alliage d’aluminium 5052 | 4 | CNC | Peut être imprimé en 3D en ABS avec remplissage 30% |
| Entretoise arrière moteurs 2–4 |  | 02_Motor_Back_Spacer.step | Alliage d’aluminium 5052 | 3 | CNC | |
| Bride arrière moteurs 2–4 |  | 02_FLANGE.step | Alliage d’aluminium 5052 | 3 | CNC | |
| Support du moteur poignet 5 |  | 02_Wrist_Bracket.step | Alliage d’aluminium 5052 | 1 | CNC | |
| Raccord préhenseur A |  | 02_Gripper_Connector_A.step | Alliage d’aluminium 5052 | 1 | CNC | |
| Raccord préhenseur B |  | 02_Gripper_Connector_B.step | Alliage d’aluminium 5052 | 1 | CNC | |
| Support métallique de coulisseau préhenseur |  | 02_Slider_Bracket.step | Alliage d’aluminium 5052 | 1 | CNC | Peut être imprimé en 3D en ABS avec fort remplissage, non recommandé pour une utilisation prolongée |
| Extension coulisseau-préhenseur |  | 02_Slider_Extension.step | Alliage d’aluminium 5052 | 2 | CNC | |
| Liaison gauche bras supérieur-bras inférieur |  | 02_Lower_Upper_Link_L.step | Alliage d’aluminium 5052 | 1 | CNC | |
| Liaison droite bras supérieur-bras inférieur |  | 02_Lower_Upper_Link_R.step | Alliage d’aluminium 5052 | 1 | CNC | |
| Liaison gauche bras inférieur-poignet |  | 02_Lower_Wrist_Link_L.step | Alliage d’aluminium 5052 | 1 | CNC | |
| Liaison droite bras inférieur-poignet |  | 02_Lower_Wrist_Link_R.step | Alliage d’aluminium 5052 | 1 | CNC | |
| Raccord de pignon |  | 02_Gear_Connector.step | Alliage d’aluminium 5052 | 1 | CNC | |
| Rack |  | 02_Rack.step | Alliage d’aluminium 5052 | 2 | CNC | |
| Liaison 1 |  | 03_Link1.step | Alliage d’aluminium 5052 | 1 | CNC + tôlerie | |
| Liaison 2 |  | 03_Link2.step | Alliage d’aluminium 5052 | 2 | CNC + tôlerie | |
| Liaison 3 gauche |  | 03_Link3_L.step | Alliage d’aluminium 5052 | 1 | CNC + tôlerie | |
| Liaison 3 droite |  | 03_Link3_R.step | Alliage d’aluminium 5052 | 1 | CNC + tôlerie | |
| Liaison 5 |  | 03_Link5.step | Alliage d’aluminium 5052 | 1 | CNC + tôlerie | |
| - | Prix de référence marché | Moyenne **250$** | | | Prix variable selon coût de l’aluminium, exigences de tolérance, délais |

### 🧩 Spécifications d’usinage
- Tolérance dimensionnelle clé : ±0.02 mm GB/T1840-M
- Finition de surface : Anodisation / sablage
- Pièces d’assemblage recommandées : ajustement H7 / ajustement serré

---

## 🛒 Pièces achetées (pièces standard)

> [!WARNING]
> Comme chacun devra assembler et serrer les vis soi-même, des vis hexagonales intérieures standard ont été sélectionnées. Après un fonctionnement prolongé, les vis peuvent se desserrer, ce qui affecte la précision du bras robotique. Pour cette raison, vous devez acheter en plus de la colle chaude pour effectuer un freinage fileté sur les vis de chaque articulation.

Si vous disposez d’une perceuse électrique ou d’outils similaires, vous pouvez choisir d’acheter des rondelles freins ou des vis freins filetées à la place. Cependant, **il est extrêmement important** d’utiliser le réglage de couple le plus bas avec un tournevis électrique pour éviter d’arracher les filets, ce qui entraînerait des dommages irréversibles.

| Nom | Spécification / Modèle | Quantité | Prix de référence | Notes |
|---|---|---|---|---|
| Moteur sans balais | DM4310(V4) | 4 | 120 $/unité | [SeeedStudio](https://www.seeedstudio.com/Damiao-4310-Actuator-Motor-p-6823.html) |
| Moteur sans balais | DM4340P(V4) | 3 | 175 $/unité | [SeeedStudio](https://www.seeedstudio.com/DM4340P-Actuator-p-6663.html) |
| Carte d’interface CAN-USB | - | 1 | 15 $/unité | [SeeedStudio](https://www.seeedstudio.com/DM-CAN-USB-Driver-Borad-p-6706.html) |
| Palier | 6707ZZ | 1 | 13 $/unité | [Amazon](https://www.amazon.com/uxcell-35x44x5mm-Shielded-Precision-Lubricated/dp/B0D6WBMW3F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) |
| Palier | 6803ZZ | 3 | 13 $/unité | [Amazon](https://www.amazon.com/uxcell-17x26x5mm-Shielded-Precision-Lubricated/dp/B0D54JSWBZ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) |
| Palier | AXK5578 | 1 | 12 $/unité | [Amazon](https://www.amazon.com/PZRT-AXK5578-Thrust-Bearings-Washers/dp/B0B3M3RZGW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) |
| Rail linéaire | MGN9-170mm | 1 | 23 $/unité | [Amazon](https://www.amazon.com/uxcell-Sliding-Carriage-Bearing-Printers/dp/B0D54L45WM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) |
| Bloc coulissant | MGN9 | 2 | 10 $/unité | [Amazon](https://www.amazon.com/uxcell-Bearing-Sliding-Carriage-Anti-Fall/dp/B0D9QBQDKB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) |
| Pignon | Module 1, type moyeu, 16 dents, alésage 6 mm | 1 | 44 $/unité | [Amazon](https://www.amazon.com/Module-15-Teeth-Finished-Perforation/dp/B0GDSR1LKM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) |
| Patin en silicone | 30x9x2mm | 1 | 10 $ | [Amazon](https://www.amazon.com/Self-Adhesive-Anti-Sliding-Anti-Scratch-Protectors-Appliances/dp/B0F9KVYXFZ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) |
| Vis | HM3-12mm | 14+ | - | [Amazon](https://www.amazon.com/BNUOK-120pcs-Stainless-Threads-Spanner/dp/B0DJQGMQZM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) |
| Vis | HM3-25mm | 14+ | - | [Amazon](https://www.amazon.com/BNUOK-120pcs-Stainless-Threads-Spanner/dp/B0DJQFGRPQ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) |
| Vis | HM3-6mm | 16+ | - | [Amazon](https://www.amazon.com/BNUOK-120pcs-Stainless-Threads-Spanner/dp/B0DJQG5YLF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) |
| Vis | HM4-75mm sans tête | 4+ | - | [Amazon](https://www.amazon.com/iexcell-Partially-Threaded-Thread-Socket/dp/B0DR1NX178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) |
| Vis | KM3×12mm fraisée | 30+ | - | [Amazon](https://www.amazon.com/Uxcell-a16011300ux0872-M3x12mm-Carbon-Countersunk/dp/B01E6EIC2S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) |
| Vis | KM3×16mm fraisée | 34+ | - | [Amazon](https://www.amazon.com/Uxcell-a16011300ux0872-M3x12mm-Carbon-Countersunk/dp/B01E6EIC2S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) |
| Vis | KM3×7mm fraisée | 76+ | - | [Amazon](https://www.amazon.com/Uxcell-a16011300ux0872-M3x12mm-Carbon-Countersunk/dp/B01E6EIC2S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) |
| Vis | KM3×9mm fraisée | 31+ | - | [Amazon](https://www.amazon.com/Uxcell-a16011300ux0872-M3x12mm-Carbon-Countersunk/dp/B01E6EIC2S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) |
| Vis | KM3×8mm fraisée à tête très basse | 31+ | - | [Amazon](https://www.amazon.com/SMALLRIG-Screw-Screws-12pcs-Pack/dp/B01MS60KSY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) |
| Vis | KA3×12mm tête bombée | 72+ | - | [Amazon](https://www.amazon.com/uxcell-Phillips-Tapping-Screws-Silver/dp/B01MXSS95N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) |
| Goupille cylindrique | M4×8mm | Plusieurs | - | [Amazon](https://www.amazon.com/HARFINGTON-Stainless-Cylindrical-Furniture-Installation/dp/B0F6CWL4MP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) |
| Goupille cylindrique | M4×12mm | Plusieurs | - | [Amazon](https://www.amazon.com/HARFINGTON-Stainless-Cylindrical-Furniture-Installation/dp/B0F6CWL4MP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) |
| Jeu de tournevis | Jeu de clés hexagonales | 1 | 16 $ | [Amazon](https://www.amazon.com/Amazon-Basics-Ratcheting-Electronics-Screwdriver/dp/B07V4TFWFZ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) |
|  | XT30 2+2 350mm | 2 | 4 $/câble | Deux extrémités coudées |
|  | XT30 2+2 350mm | 1 | 4 $/câble | Une extrémité coudée, une droite |
|  | XT30 2+2 200mm | 3 | 4 $/câble | Deux extrémités coudées |
|  | XT30 2+2 200mm | 1 | 3 $/câble | Deux extrémités droites |

### Concernant la fixation
Vous pouvez modifier librement la base à l'aide des pièces imprimées en 3D fournies. Vous pouvez également utiliser des serre-joints en fonction de l'épaisseur de votre plateau de table.

| Désignation | Spécifications / Référence | Quantité | Prix de référence | Remarques |
|---|---|---|---|---|
| Serre-joint à bois | Serre-joint G de 6 pouces | 2 | 20 $/unité | [Amazon](https://www.amazon.com/gp/aw/d/B092J1YW2M/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) |

### Concernant l'alimentation électrique
Le bras robotique est livré sans alimentation d'origine. Vous pouvez brancher votre propre batterie ou acheter une alimentation fiable MeanWell de 24V 14,6A fabriquée à Taïwan. De plus, vous devrez vous procurer une fiche trois broches conforme aux normes locales ainsi qu'un faisceau de câbles équipé d'un connecteur femelle XT30.

#### Nomenclature des consommables

| Désignation | Spécifications | Qté | Prix de référence | Remarques | Image |
|:---|:---|:---:|:---:|:---|:---:|
| Alimentation | LRS-350-24 (24V 14,6A) | 1 | 27,35 $ | [amazon](https://www.amazon.com/MEAN-WELL-LRS-350-24-350-4W-Switchable/dp/B013ETVO12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) |  |
| Cordon d'alimentation | Câble secteur standard US | 1 | 4,49 $ | [amazon](https://www.amazon.com/LIFEPOE-Power-3-3ft-Black-3-Prong/dp/B0FK4KPW2G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) |  |
| Port de sortie | Connecteur femelle fixe XT60E ; XT60E femelle + cosse - 10 cm ; trou de cosse 4 mm | 1 | 9,99 $ | [amazon](https://www.amazon.com/LINSYRC-XT60E-F-Connector-Battery-Quadcopter/dp/B0CQK1P1DP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) |  |
| Câblage secteur | 1,5 mm² ; rouge, bleu, jaune, 1 de chaque (l'utilisateur doit sertir lui-même les cosses sur les fils — cordons pré-sertis non fournis) ; 10 cm | 3 | 0,99 $ | [aliexpress](https://www.aliexpress.com/item/1005008648016252.html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) |  |
| Prise IEC 3-en-1 | Type à connexion rapide avec interrupteur rouge (double écrou) | 1 | 1,98 $ | [aliexpress](https://www.aliexpress.com/item/1005005962021242.html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) |  |
| Câble adaptateur XT30 vers XT60 | XT30U femelle vers XT60 mâle | 1 | 8,99 $ | [amazon](https://www.amazon.com/dp/B0BY8PSHK6?th=1) |  |
| Vis à tête fraisée cruciforme inox 304 | M4x6 | 6 | 0,37 $ | / | / |
| Vis à tête fraisée cruciforme inox 304 | M3x8 | 2 | 0,36 $ | / | / |
| Vis à tête bombée cruciforme inox 304 | M3x8 | 2 | 0,32 $ | / | / |
| Écrou hexagonal | M3x2,5 | 2 | 2,10 CNY | / | / |

#### Nomenclature des pièces imprimées

| Désignation | Image | Qté | Notes |
|:---|:---|:---:|:---|
| [Capot avant](./3D_Printed_Parts/DM-power-Top%20Cover.stp) |  | 1 | PLA, buse 0,4 mm, hauteur de couche 0,2 mm, remplissage 30 % |
| [Capot arrière](./3D_Printed_Parts/DM-power-Bottom%20Cover.stp) |  | 1 | PLA, buse 0,4 mm, hauteur de couche 0,2 mm, remplissage 30 % |
| [Capot avant coulissant](./3D_Printed_Parts/DM-power-Top%20Cover-Sliding%20Cover.stp) |  | 1 | PLA, buse 0,4 mm, hauteur de couche 0,2 mm, remplissage 30 % |

#### Assemblage de l'alimentation

L'assemblage de l'alimentation se divise en deux parties principales : le capot avant et le capot arrière.

##### 1. Assemblage du capot avant

| Étape | Instructions | Image | Remarques |
|:---:|---|---|---|
| 1-1 | Préparer les pièces et les pièces imprimées nécessaires à l'assemblage du capot avant |  | Vérifier que toutes les pièces sont présentes |
| 1-2 | Explication de l'ordre de câblage de chaque pièce ; assembler en respectant cet ordre | <br> | Raccorder strictement selon l'ordre de câblage |
| 1-3 | Installer le connecteur XT60 |  | Fixer avec des vis à tête fraisée cruciforme inox 304 M3x8 et des écrous hexagonaux M3x2,5 |
| 1-4 | Installer la prise IEC 3-en-1 |  | Fixer la prise IEC 3-en-1 avec des vis à tête bombée cruciforme inox 304 M3x8 |
| 1-5 | Câblage interne du capot avant | <br> | Vérifier les raccordements à l'aide du schéma d'ordre de câblage |
| 1-6 | Fixer les deux côtés du capot avant et l'alimentation |  | Vis à tête fraisée cruciforme inox 304 M4x6 x2 |
| 1-7 | Installer le capot coulissant |  | Insérer par le dessous de l'alimentation |
| 1-8 | Fixer le capot coulissant |  | Vis à tête fraisée cruciforme inox 304 M4x6 x2 |

---

##### 2. Assemblage du capot arrière

| Étape | Instructions | Image | Remarques |
|:---:|---|---|---|
| 2-1 | Préparer les pièces et les pièces imprimées nécessaires à l'assemblage du capot arrière |  | Vérifier que les accessoires sont complets |
| 2-2 | Assembler le capot arrière avec l'alimentation |  | Aligner la position |
| 2-3 | Fixer les deux côtés du capot arrière et l'alimentation |  | Vis à tête fraisée cruciforme inox 304 M4x6 x2 |

---

##### 3. Assemblage terminé

| Étape | Instructions | Image | Remarques |
|:---:|---|---|---|
| 1 | Assemblage de la solution d'alimentation terminé |  | Vérifier que toutes les vis sont serrées |

---

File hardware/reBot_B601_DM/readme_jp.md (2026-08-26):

# 🤖 reBot DevArm オープンソースハードウェア仕様書

<p align="center">
  reBot-DevArm バナー
</p>
<p align="center">
  <strong>
    <a href="./readme_zh.md">简体中文</a> &nbsp;|&nbsp;
    <a href="./readme.md">English</a> &nbsp;|&nbsp;
    <a href="./readme_jp.md">日本語</a>&nbsp;|&nbsp;
    <a href="./readme_fr.md">français</a>&nbsp;|&nbsp;
    <a href="./readme_es.md">Español</a>
  </strong>
</p>

| 日付 | バージョン | ファイル名 | 変更履歴 |
|---|---|---|---|
| 2026-03-31 | v1.0 | reBot_B601_DM_v1.0_20260331.step | 初回アップロード |
| 2026-04-15 | v1.1 | reBot_B601_DM_v1.1_20260415.step | エンドジョイント3つのモーターにケーブル拘束を追加し、緩みや外れを防止。ジョイント1のモデルを4310から4340Pに修正。ベース剛性を高めるため、底部にCNCパーツ 02_Base_Reinforcement_Part.step を追加。 |

このBOMは、大疆43シリーズモーターを使用する reBot Arm B601 DM ロボットアーム用です。もう一方のバージョンである reBot Arm B601 RS は RobStride モーターを使用しています。[BOMはこちら](../reBot_B601_RS/README.md)をご覧ください。

# 📦 ファイル構成
*   3D_Printed_Parts/: すべての3Dプリント部品のStepファイル。
*   Metal_Parts/: すべてのCNC加工金属部品のStepファイル。
*   Purchased_Parts/: すべての購入部品のStepファイル。
*   reBot_B601_DM_v1.1_20260415.step: ロボットアームのフルアセンブリファイル。

# 🛒[全部品を入手](https://www.seeedstudio.com/reBot-Arm-B601-DM-Bundle.html)
- 5種類のキットオプションを提供しています：
  - **アームボディモーターキット**: ロボットアーム用のモーターと配線ハーネスのみを含む。
  - **アームボディ構造キット**: 機械的構造部品のみを含む。
  - **グリッパーコンプリートキット**: グリッパー用のモーター、配線ハーネス、構造部品を含む。
  - **フルキット**: ロボットアーム本体とグリッパーの完全なセットを含む。
  - **組立済みロボットアーム**: 完全に組み立てられた完成品のロボットアーム。

# 📊 部品表 (BOM)

> [!WARNING]
> 宣言: 公開されているBOMは、Seeedからの最終出荷バージョンを**示すものではありません**。このオープンソースv1.1は、開発者が最小コストで再現できるように最適化されており、一部の必須でない詳細は簡略化されています。
> Seeedの最終生産バージョンには、誤動作防止のための金属レーザー刻印、耐久性のために一部の3Dプリント部品を金属に置き換え、工場でのばらつきに対応するためのクリアランスと加工公差の調整（精度とコストのバランス）、および追加コストでのカスタム配線（例：組み紐スリーブ保護）が含まれます。ただし、機械的構造は同一です。

---

## 🖨️ 3Dプリント部品

| 部品説明 | 画像 | ファイル名 | 材料 | 数量 | 注記 |
|---|---|---|---|---|---|
| ロボットアームベースプラットフォーム |  | 01_BASE_Plate.step | Bambu ABS Black | 1 | 0.4mmノズル、0.2mmレイヤー高さ、30%インフィル |
| ロボットアームベースリンク |  | 01_BASE_Link.step | Bambu ABS Black | 1 | 0.4mmノズル、0.2mmレイヤー高さ、30%インフィル |
| 上アーム左フィラー |  | 01_Upper_Arm_Fuller_L.step | Bambu PLA Black & Green | 1 | 0.4mmノズル、0.2mmレイヤー高さ、15%インフィル |
| 上アーム右フィラー |  | 01_Upper_Arm_Fuller_R.step | Bambu PLA Black & Green | 1 | 0.4mmノズル、0.2mmレイヤー高さ、15%インフィル |
| 上アーム中央フィラー |  | 01_Upper_Arm_Fuller_M.step | Bambu ABS Black | 1 | 0.4mmノズル、0.2mmレイヤー高さ、30%インフィル |
| 上アーム水平リミットブロック |  | 01_Upper_Arm_Limit.step | Bambu ABS Black | 1 | 0.4mmノズル、0.2mmレイヤー高さ、30%インフィル |
| アームハンドル |  | 01_Arm_Handle.step | Bambu ABS Black | 1 | 0.4mmノズル、0.2mmレイヤー高さ、30%インフィル |
| 下アーム左フィラー |  | 01_Lower_Arm_Filler_L.step | Bambu PLA Black & Green | 1 | 0.4mmノズル、0.2mmレイヤー高さ、15%インフィル |
| 下アーム右フィラー |  | 01_Lower_Arm_Filler_R.step | Bambu PLA Black & Green | 1 | 0.4mmノズル、0.2mmレイヤー高さ、15%インフィル |
| 下アーム中央フィラー |  | 01_Lower_Arm_Filler_M.step | Bambu ABS Black | 1 | 0.4mmノズル、0.2mmレイヤー高さ、30%インフィル |
| 上アームカバー |  | 01_Upper_Arm_Cover.step | Bambu PLA Green | 1 | 0.4mmノズル、0.2mmレイヤー高さ、15%インフィル |
| 下アームカバー |  | 01_Lower_Arm_Cover.step | Bambu PLA Green | 1 | 0.4mmノズル、0.2mmレイヤー高さ、15%インフィル |
| モーター5保護カバー |  | 01_Motor_Cover.step | Bambu ABS Black | 1 | 0.4mmノズル、0.2mmレイヤー高さ、30%インフィル |
| グリッパー水平リミット |  | 01_Lower_Arm_Limit.step | Bambu PLA Green | 1 | 0.4mmノズル、0.2mmレイヤー高さ、15%インフィル |
| グリッパースライダーサポートブラケット |  | 01-Rail-Bracket.step | Bambu PLA Green | 1 | 0.4mmノズル、0.2mmレイヤー高さ、15%インフィル |
| グリッパーフィンガー |  | 01_Finger.step | Bambu ABS Black | 2 | 0.4mmノズル、0.2mmレイヤー高さ、45%インフィル |
| モーター5 ケーブル拘束 |  | 01_Joint5_Cable Restraint_A.step | Bambu PLA Green | 1 | 0.4mmノズル、0.2mmレイヤー高さ、15%インフィル |
| モーター6＆7 ケーブル拘束 A |  | 01_Joint6_7_Cable Restraint_A.step | Bambu ABS Black | 2 | 0.4mmノズル、0.2mmレイヤー高さ、30%インフィル |
| モーター6＆7 ケーブル拘束 B |  | 01_Joint6_7_Cable Restraint_B.step | Bambu ABS Black | 2 | 0.4mmノズル、0.2mmレイヤー高さ、30%インフィル |
| - | 参考価格 | 平均 **50$** | | | 材料費と印刷時間により価格変動 |

配線ハーネス1を長期間引き回して使用すると、モーター側コネクタが摩耗し、接触不良が発生する可能性があります。
下記の部品を3Dプリンタで造形することで、この不具合リスクを抑えられます。

| 部品詳細 | 画像 | ファイル名 | 材質 | 個数 | 備考 |
| ---- | ---- | ---- | ---- | ---- | ---- |
| 1号モーター両面用配線ハーネスクリップ |  | `DM_Motor1_wiring_harness_clip.stp` | Bambu Lab 黒ABS樹脂 | 2個 | ノズル径0.4mm、積層ピッチ0.2mm、充填率30% |

## 📷 対応カメラマウント

| 部品説明 | 画像 | ファイル名 | 材料 | 数量 | 注記 |
|---|---|---|---|---|---|
| [Orbbec Gemini2](https://www.seeedstudio.com/Orbbec-Gemini-2-3D-Camera-p-6464.html) |  | [`D435_Gemini2_Mount.step`](./3D_Printed_Parts/D435_Gemini2_Mount.step) | Bambu ABS Black | 1 | 0.4mmノズル、0.2mmレイヤー高さ、30%インフィル |

### 🧩 印刷推奨事項
- レイヤー高さ: 0.2 mm
- ノズル: 0.4 mm
- サポート: 必要に応じて追加
- 材料: 高温・耐荷重部品にはABS（インフィル30～80%）、ナイロンまたはカーボン繊維強化材料も可。外装部品にはPLA（インフィル15%）。
- 耐荷重部品の推奨材料：

---

## 🔩 CNC加工金属部品

> [!WARNING]
> 注記に記載されている一部の部品は3Dプリントに置き換え可能で、コストを大幅に削減できます。

| 部品説明 | 画像 | ファイル名 | 材料 | 数量 | 加工 | 注記 |
|---|---|---|---|---|---|---|
| モーター1 ベアリングマウント |  | 02_Base_Reinforcement_Part.step | アルミニウム合金 5052 | 1 | CNC | コスト削減のため、高インフィルABSで3Dプリント可能 |
| モーター1 回転軸 |  | 02_Arm_Yaw_Limit.step | アルミニウム合金 5052 | 1 | CNC | ヨー角運動制限を追加 |
| モーター2–5 フロントスペーサー |  | 02_Motor_Front_Spacer.step | アルミニウム合金 5052 | 4 | CNC | ABS、インフィル30%で3Dプリント可能 |
| モーター2–4 リアスペーサー |  | 02_Motor_Back_Spacer.step | アルミニウム合金 5052 | 3 | CNC | |
| モーター2–4 リアフランジ |  | 02_FLANGE.step | アルミニウム合金 5052 | 3 | CNC | |
| 手首モーター5 ブラケット |  | 02_Wrist_Bracket.step | アルミニウム合金 5052 | 1 | CNC | |
| グリッパーコネクタ A |  | 02_Gripper_Connector_A.step | アルミニウム合金 5052 | 1 | CNC | |
| グリッパーコネクタ B |  | 02_Gripper_Connector_B.step | アルミニウム合金 5052 | 1 | CNC | |
| グリッパースライダー金属ブラケット |  | 02_Slider_Bracket.step | アルミニウム合金 5052 | 1 | CNC | 高インフィルABSで3Dプリント可能だが、長期使用は非推奨 |
| スライダーからグリッパーへの延長部 |  | 02_Slider_Extension.step | アルミニウム合金 5052 | 2 | CNC | |
| 上下アームリンク左 |  | 02_Lower_Upper_Link_L.step | アルミニウム合金 5052 | 1 | CNC | |
| 上下アームリンク右 |  | 02_Lower_Upper_Link_R.step | アルミニウム合金 5052 | 1 | CNC | |
| 下アーム-手首リンク左 |  | 02_Lower_Wrist_Link_L.step | アルミニウム合金 5052 | 1 | CNC | |
| 下アーム-手首リンク右 |  | 02_Lower_Wrist_Link_R.step | アルミニウム合金 5052 | 1 | CNC | |
| ギアコネクタ |  | 02_Gear_Connector.step | アルミニウム合金 5052 | 1 | CNC | |
| ラック |  | 02_Rack.step | アルミニウム合金 5052 | 2 | CNC | |
| リンク 1 |  | 03_Link1.step | アルミニウム合金 5052 | 1 | CNC + 板金 | |
| リンク 2 |  | 03_Link2.step | アルミニウム合金 5052 | 2 | CNC + 板金 | |
| リンク 3 左 |  | 03_Link3_L.step | アルミニウム合金 5052 | 1 | CNC + 板金 | |
| リンク 3 右 |  | 03_Link3_R.step | アルミニウム合金 5052 | 1 | CNC + 板金 | |
| リンク 5 |  | 03_Link5.step | アルミニウム合金 5052 | 1 | CNC + 板金 | |
| - | 市場参考価格 | 平均 **250$** | | | アルミニウムコスト、公差要件、納期により価格変動 |

### 🧩 加工仕様
- 主要寸法公差: ±0.02 mm GB/T1840-M
- 表面仕上げ: アルマイト / サンドブラスト
- 嵌合部品推奨: H7 / インターフェリンスフィット
---

## 🛒 購入部品 (標準部品)

> [!WARNING]
> 組み立て・ネジ締めはご自身で行っていただく必要があるため、標準的な六角穴付きネジを選択しています。長時間の動作後、ネジが緩み、ロボットアームの精度に影響を与える可能性があります。そのため、各ジョイントのネジにネジロックを行うためのホットメルト接着剤を別途購入する必要があります。

電動ドリルなどの工具をお持ちの場合は、代わりにロックワッシャーやネジロック剤付きネジを購入しても構いません。ただし、電動ドライバーを使用する際は**非常に重要なこと**ですが、ネジ山をなめないように最も低いトルク設定を使用してください。ネジ山をなめると、元に戻せない損傷が発生します。

| 名前 | 仕様 / モデル | 数量 | 参考価格 | 注記 |
|---|---|---|---|---|
| ブラシレスモーター | DM4310(V4) | 4 | 120 $/unit | [SeeedStudio](https://www.seeedstudio.com/Damiao-4310-Actuator-Motor-p-6823.html) |
| ブラシレスモーター | DM4340P(V4) | 3 | 175 $/unit | [SeeedStudio](https://www.seeedstudio.com/DM4340P-Actuator-p-6663.html) |
| CAN-USBドライバーボード | | 1 | 15 $/unit | [SeeedStudio](https://www.seeedstudio.com/DM-CAN-USB-Driver-Borad-p-6706.html) |
| ベアリング | 6707ZZ | 1 | 13 $/unit | [Amazon](https://www.amazon.com/uxcell-35x44x5mm-Shielded-Precision-Lubricated/dp/B0D6WBMW3F/ref=sr_1_1) |
| ベアリング | 6803ZZ | 3 | 13 $/unit | [Amazon](https://www.amazon.com/uxcell-17x26x5mm-Shielded-Precision-Lubricated/dp/B0D54JSWBZ/ref=sr_1_1) |
| ベアリング | AXK5578 | 1 | 12 $/unit | [Amazon](https://www.amazon.com/PZRT-AXK5578-Thrust-Bearings-Washers/dp/B0B3M3RZGW/ref=sr_1_1) |
| リニアレール | MGN9-170mm | 1 | 23 $/unit | [Amazon](https://www.amazon.com/uxcell-Sliding-Carriage-Bearing-Printers/dp/B0D54L45WM/ref=sr_1_1) |
| スライダーブロック | MGN9 | 2 | 10 $/unit | [Amazon](https://www.amazon.com/uxcell-Bearing-Sliding-Carriage-Anti-Fall/dp/B0D9QBQDKB/ref=sr_1_8) |
| ギア | モジュール1、ボス型、16歯、ボア6mm | 1 | 44$/unit | [Amazon](https://www.amazon.com/Module-15-Teeth-Finished-Perforation/dp/B0GDSR1LKM/ref=sr_1_1) |
| シリコンパッド | 30x9x2mm | 1 | 10 $ | [Amazon](https://www.amazon.com/Self-Adhesive-Anti-Sliding-Anti-Scratch-Protectors-Appliances/dp/B0F9KVYXFZ/ref=sr_1_3) |
| ネジ | HM3-12mm ネジ | 14+ | | [Amazon](https://www.amazon.com/BNUOK-120pcs-Stainless-Threads-Spanner/dp/B0DJQGMQZM/ref=sr_1_4) |
| ネジ | HM3-25mm ネジ | 14+ | | [Amazon](https://www.amazon.com/BNUOK-120pcs-Stainless-Threads-Spanner/dp/B0DJQFGRPQ/ref=sr_1_4) |
| ネジ | HM3-6mm ネジ | 16+ | | [Amazon](https://www.amazon.com/BNUOK-120pcs-Stainless-Threads-Spanner/dp/B0DJQG5YLF/ref=sr_1_4) |
| ネジ | HM4-75mm 止めネジ | 4+ | | [Amazon](https://www.amazon.com/iexcell-Partially-Threaded-Thread-Socket/dp/B0DR1NX178/ref=sr_1_1) |
| ネジ | KM3*12mm ネジ | 30+ | | [Amazon](https://www.amazon.com/Uxcell-a16011300ux0872-M3x12mm-Carbon-Countersunk/dp/B01E6EIC2S/ref=sr_1_1) |
| ネジ | KM3*16mm ネジ | 34+ | | [Amazon](https://www.amazon.com/Uxcell-a16011300ux0872-M3x12mm-Carbon-Countersunk/dp/B01E6EIC2S/ref=sr_1_1) |
| ネジ | KM3*7mm ネジ | 76+ | | [Amazon](https://www.amazon.com/Uxcell-a16011300ux0872-M3x12mm-Carbon-Countersunk/dp/B01E6EIC2S/ref=sr_1_1) |
| ネジ | KM3*9mm ネジ | 31+ | | [Amazon](https://www.amazon.com/Uxcell-a16011300ux0872-M3x12mm-Carbon-Countersunk/dp/B01E6EIC2S/ref=sr_1_1) |
| ネジ | KM3*8mm マイクロプロファイル六角穴付きネジ | 31+ | | [Amazon](https://www.amazon.com/SMALLRIG-Screw-Screws-12pcs-Pack/dp/B01MS60KSY/ref=sr_1_1) |
| ネジ | KA3*12mm | 72+ | | [Amazon](https://www.amazon.com/uxcell-Phillips-Tapping-Screws-Silver/dp/B01MXSS95N/ref=sr_1_3) |
| 位置決めピン | M4*8mm | 数本 | | [Amazon](https://www.amazon.com/HARFINGTON-Stainless-Cylindrical-Furniture-Installation/dp/B0F6CWL4MP/ref=sr_1_6) |
| 位置決めピン | M4*12mm | 数本 | | [Amazon](https://www.amazon.com/HARFINGTON-Stainless-Cylindrical-Furniture-Installation/dp/B0F6CWL4MP/ref=sr_1_6) |
| ドライバーセット | 六角レンチセット | 1 | 16$ | [Amazon](https://www.amazon.com/Amazon-Basics-Ratcheting-Electronics-Screwdriver/dp/B07V4TFWFZ/ref=sr_1_2) |
|  | XT30 2+2 350mm | 2 | 4 $/cable | 両端アングル |
|  | XT30 2+2 350mm | 1 | 4 $/cable | 一端アングル、一端ストレート |
|  | XT30 2+2 200mm | 3 | 4 $/cable | 両端アングル |
|  | XT30 2+2 200mm | 1 | 3 $/cable | 両端ストレート |

### 固定方法について
付属の3Dプリント部品を基に、土台を自由に加工していただけます。机の天板の厚さに合わせて、Gクランプを使用することも可能です。

| 名称 | 仕様/型式 | 数量 | 参考価格 | 備考 |
|---|---|---|---|---|
| 木工用クランプ | 6インチ Gクランプ | 2個 | 1個あたり20ドル | [Amazon](https://www.amazon.com/gp/aw/d/B092J1YW2M/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) |

### 電源について
本ロボットアームは標準で電源が付属しておりません。お手持ちのバッテリーを接続するか、台湾製の信頼性の高い**24V 14.6A MeanWell製電源**を別途ご購入ください。
加えて、現地基準に適合した3ピンプラグ、及びXT30メスコネクタ付き配線ハーネスもご用意いただく必要があります。

#### 消耗品BOM

| 名称 | 仕様 | 数量 | 参考価格 | 備考 | 画像 |
|:---|:---|:---:|:---:|:---|:---:|
| 電源装置 | LRS-350-24 (24V 14.6A) | 1 | 27.35ドル | [amazon](https://www.amazon.com/MEAN-WELL-LRS-350-24-350-4W-Switchable/dp/B013ETVO12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) |  |
| 電源コード | 米国規格ACケーブル | 1 | 4.49ドル | [amazon](https://www.amazon.com/LIFEPOE-Power-3-3ft-Black-3-Prong/dp/B0FK4KPW2G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) |  |
| 出力ポート | XT60E 固定メスコネクタ／XT60E メス＋圧着端子 - 10cm／端子穴 4mm | 1 | 9.99ドル | [amazon](https://www.amazon.com/LINSYRC-XT60E-F-Connector-Battery-Quadcopter/dp/B0CQK1P1DP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) |  |
| AC電源配線 | 1.5mm²、赤・青・黄 各1本（端子はご自身で圧着してください。圧着済みリード線は付属しません）、10cm | 3 | 0.99ドル | [aliexpress](https://www.aliexpress.com/item/1005008648016252.html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) |  |
| 三合一 IEC インレットソケット | 赤色スイッチ付きクイックコネクトタイプ（ダブルナット） | 1 | 1.98ドル | [aliexpress](https://www.aliexpress.com/item/1005005962021242.html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) |  |
| XT30-XT60 変換ケーブル | XT30U メス - XT60 オス | 1 | 8.99ドル | [amazon](https://www.amazon.com/dp/B0BY8PSHK6?th=1) |  |
| 304ステンレス 十字穴付き皿ねじ | M4x6 | 6 | 0.37ドル | / | / |
| 304ステンレス 十字穴付き皿ねじ | M3x8 | 2 | 0.36ドル | / | / |
| 304ステンレス 十字穴付きなべねじ | M3x8 | 2 | 0.32ドル | / | / |
| 六角ナット | M3x2.5 | 2 | 2.10 CNY | / | / |

#### プリント部品BOM

| 名称 | 画像 | 数量 | 備考 |
|:---|:---|:---:|:---|
| [フロントカバー](./3D_Printed_Parts/DM-power-Top%20Cover.stp) |  | 1 | PLA、0.4mmノズル、0.2mmレイヤー高さ、30%インフィル |
| [リアカバー](./3D_Printed_Parts/DM-power-Bottom%20Cover.stp) |  | 1 | PLA、0.4mmノズル、0.2mmレイヤー高さ、30%インフィル |
| [フロントカバー スライドカバー](./3D_Printed_Parts/DM-power-Top%20Cover-Sliding%20Cover.stp) |  | 1 | PLA、0.4mmノズル、0.2mmレイヤー高さ、30%インフィル |

#### 電源の組み立て

電源の組み立ては、フロントカバーとリアカバーの二つの工程に分かれます。

##### 1. フロントカバーの組み立て

| Step | 操作手順 | 画像 | 備考 |
|:---:|---|---|---|
| 1-1 | フロントカバーの組み立てに必要な部品とプリント部品を準備する |  | 部品がすべて揃っているか確認してください |
| 1-2 | 各部品の結線順序の説明。結線順序に従って組み立てる | <br> | 必ず結線順序どおりに接続してください |
| 1-3 | XT60 コネクタを取り付ける |  | 304ステンレス十字穴付き皿ねじ M3x8 と六角ナット M3x2.5 で固定します |
| 1-4 | 三合一 IEC ソケットを取り付ける |  | 三合一 IEC ソケットを304ステンレス十字穴付きなべねじ M3x8 で固定します |
| 1-5 | フロントカバー内部の配線 | <br> | 結線順序図と照らし合わせて接続を確認してください |
| 1-6 | フロントカバーと電源の両側を固定する |  | 304ステンレス十字穴付き皿ねじ M4x6 ×2 |
| 1-7 | スライドカバーを取り付ける |  | 電源の下側から差し込みます |
| 1-8 | スライドカバーを固定する |  | 304ステンレス十字穴付き皿ねじ M4x6 ×2 |

---

##### 2. リアカバーの組み立て

| Step | 操作手順 | 画像 | 備考 |
|:---:|---|---|---|
| 2-1 | リアカバーの組み立てに必要な部品とプリント部品を準備する |  | 付属品がすべて揃っているか確認してください |
| 2-2 | リアカバーと電源を組み合わせる |  | 位置を合わせてください |
| 2-3 | リアカバーと電源の両側を固定する |  | 304ステンレス十字穴付き皿ねじ M4x6 ×2 |

---

##### 3. 組み立て完了

| Step | 操作手順 | 画像 | 備考 |
|:---:|---|---|---|
| 1 | 電源ソリューションの組み立てが完了しました |  | すべてのねじが締まっているか確認してください |

---

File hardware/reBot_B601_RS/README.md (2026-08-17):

# 🤖 reBot DevArm Open Source Hardware Specification

<p align="center">
  reBot-DevArm Banner
</p>
<p align="center">
  <strong>
    <a href="./README_zh.md">简体中文</a> &nbsp;|&nbsp;
    <a href="./README.md">English</a> &nbsp;|&nbsp;
    <a href="./README_fr.md">français</a>&nbsp;|&nbsp;
    <a href="./README_es.md">Español</a>
  </strong>
</p>

| Date | Version | File Name | Changelog |
|---|---|---|---|
|  2026-07-09 | v1.0 |  reBot_B601_RS_v1.0_20260625.step  | Initial upload |

This BOM is for the reBot Arm B601 RS robotic arm, which uses ROBOSTRIDE series motors. The other version, reBot Arm B601 DM, uses DAMIAO motors; [see the BOM here](../reBot_B601_DM/readme.md).

# 📦 File Structure
*   3D_Printed_Parts/: Step files for all 3D printed parts.
*   Metal_Parts/: Step files for all CNC machined metal parts.
*   Purchased_Parts/: Step files for all purchased components.
*   reBot_B601_RS_v1.0_20260625.step: Full robotic arm assembly file.

# 🛒[Gets All Parts](https://www.seeedstudio.com/reBot-Arm-B601-RS-Disassembly-Kit-Version-with-Power-Supply-Bundle.html)
- We offer five kit options:
  - **reBot-Arm-B601-RS-Disassembly-Kit**
  - **reBot-Arm-B601-RS-Assembly-Version**

# 📊 Bill of Materials (BOM)

> [!WARNING]
> Declaration: The published BOM does **not** represent the final shipping version from Seeed. This open-source v1.0 is optimized for developers to reproduce at minimal cost, with some non-essential details simplified.
> The final Seeed production version will include metal laser engraving for foolproofing, some 3D printed parts will be replaced with metal for durability, clearances and machining tolerances will be adjusted for factory variation (balancing precision and cost), and custom wiring (e.g., braided sleeve protection) will be added at extra cost. However, the mechanical structure remains identical.

---

## 🖨️ 3D Printed Parts

| Part Description | Image | File Name | Material | Qty | Notes |
|---|---|---|---|---|---|
| Robotic Arm Base Platform |  | 1-BASE-PLATE.step | Bambu ABS Black | 1 | 0.4 nozzle, 0.2 layer height, 30% infill |
| Robotic Arm Base Link |  | 1-RSM1-STATOR-1.step | Bambu ABS Black | 1 | 0.4 nozzle, 0.2 layer height, 30% infill |
| Upper Arm Left Filler |  | 1-DOWN-DL.step | Bambu PLA Black & Green | 1 | 0.4 nozzle, 0.2 layer height, 15% infill |
| Upper Arm Right Filler |  | 1-DOWN-DR.step | Bambu PLA Black & Green | 1 | 0.4 nozzle, 0.2 layer height, 15% infill |
| Upper Arm and Lower Arm Center Filler |  | 1-SPACE-UP.step | Bambu ABS Black | 2 | 0.4 nozzle, 0.2 layer height, 30% infill |
| Arm Handle |  | 1-HANDLE.step | Bambu ABS Black | 1 | 0.4 nozzle, 0.2 layer height, 30% infill |
| Upper and Lower Arm Cover |  | 1-COVER.step | Bambu PLA Green | 2 | 0.4 nozzle, 0.2 layer height, 15% infill |
| Lower Arm Left Filler |  | 1-UP-DL.step | Bambu PLA Black & Green | 1 | 0.4 nozzle, 0.2 layer height, 15% infill |
| Lower Arm Right Filler |  | 1-UP-DR.step | Bambu PLA Black & Green | 1 | 0.4 nozzle, 0.2 layer height, 15% infill |
| Gripper Horizontal Limit |  | 1-STOPPER-1.step | Bambu PLA Green | 1 | 0.4 nozzle, 0.2 layer height, 15% infill |
| Gripper Slider Support Bracket |  | 1-RAIL-BASE-2.step | Bambu PLA Green | 1 | 0.4 nozzle, 0.2 layer height, 15% infill |
| Gripper Finger |  | 1-CLIP.step | Bambu ABS Black | 2 | 0.4 nozzle, 0.2 layer height, 45% infill. Print from the side of the gripper to improve its structural strength. |

Long-term dragging of Wiring Harness 1 may abrade the motor connector and result in poor electrical contact. Printing the parts listed below can mitigate this risk.

| Part Description | Image | File Name | Material | Qty | Remarks |
| ---- | ---- | ---- | ---- | ---- | ---- |
| Wiring Harness Clips for Two Sides of Motor 1 |  | `RS_Motor1_wiring_harness_clip.stp` | Bambu Lab Black ABS | 2 | 0.4 mm nozzle, 0.2 mm layer height, 30% infill |

### 🧩 Printing Recommendations
- Layer height: 0.2 mm
- Nozzle: 0.4 mm
- Supports: Add as needed
- Materials: High-temperature and load-bearing parts use ABS with 30–80% infill; may also use nylon or carbon-fiber reinforced materials. Cosmetic parts use PLA with 15% infill.
- Recommended materials for load-bearing parts:

---

## 🔩 CNC Machined Metal Parts

> [!WARNING]
> Some parts that can be replaced with 3D printing are noted in the remarks, which can significantly reduce costs.

| Part Description | Image | File Name | Material | Qty | Machining | Notes |
|---|---|---|---|---|---|---|
| Motor 1 Bearing Mount |  | 2-RSM1-ROTOR-1.step | Aluminum Alloy 5052 | 1 | CNC |  |
| Link1 Left Metal |  | 2-RSM-ROTOR-L.step | Aluminum Alloy 5052 | 1 | CNC |  |
| Link1 Right Metal |  | 2-RSM-ROTOR-R.step | Aluminum Alloy 5052 | 4 | CNC ||
| Link1 Bottom Metal |  | 2-RSM1-ROTOR-1.step | Aluminum Alloy 5052 | 3 | CNC | |
| Joint Metal Disc  |  | 2-CD.step | Aluminum Alloy 5052 | 3 | CNC | Used to Conceal Screws |
| RS06 Front Extesnion |  | 2-RSM2-STATOR-1.step | Aluminum Alloy 5052 | 2 | CNC | |
| RS06 Back Extesnion |  | 2-RSM2-STATOR-2.step | Aluminum Alloy 5052 | 2 | CNC | |
| Link2 Left and Right Metal |  | 2-LINK-2_3.step | Aluminum Alloy 5052 | 2 | CNC | |
| Upper Limit L |  | 2-Upper-Limit_L.stp | Aluminum Alloy 5052 | 1 | CNC | |
| Upper Limit R |  | 2-Upper-Limit_R.stp | Aluminum Alloy 5052 | 1 | CNC | |
| Lower & Upper Link L|  | 2-RSM3-ROTATOR-L.step | Aluminum Alloy 5052 | 1 | CNC | |
| Lower & Upper Link R|  | 2-RSM3-ROTATOR-R.step | Aluminum Alloy 5052 | 1 | CNC | |
| Link3 Left Metal|  | 2-LINK-3_4-L.step | Aluminum Alloy 5052 | 1 | CNC | |
| Link3 Right Metal|  | 2-LINK-3_4-R.step | Aluminum Alloy 5052 | 1 | CNC | |
| Link3 Right & Left Link |  | 2-SPACE-UP-2.step | Aluminum Alloy 5052 | 1 | CNC | |
| Motor4-7 Cable Fixing |  | 1-O-CLIP.step | Aluminum Alloy 5052 | 4 | CNC | Seeedstudio ships this part as a single CNC-machined metal component integrated with another part, which drives up manufacturing costs. If you reproduce the hardware on your own, you can 3D-print this part with ABS material and install M2 nuts at the positions marked by red arrows. |
| Motor4 Back Cable |  | 2-Motor_Back_Spacer.step | Aluminum Alloy 5052 | 1 | CNC |  |
| Link4-5_L |  | 2-LINK-4_5-L.step | Aluminum Alloy 5052 | 1 | CNC | |
| Link4-5_R |  | 2-LINK-4_5-R.step | Aluminum Alloy 5052 | 1 | CNC | |
| Link5 |  | 2-RSM5-STATOR.step | Aluminum Alloy 5052 | 1 | CNC | |
|Wrist_Connector_A |  | 2-RSM6-RORATOR-1.step | Aluminum Alloy 5052 | 1 | CNC |  |
|Wrist_Connector_B |  | 2-RSM6-RORATOR-2.step | Aluminum Alloy 5052 | 1 | CNC |  |
| Gripper Connector A |  | 2-M6-ROTOR.step  | Aluminum Alloy 5052 | 1 | CNC | |
| Gripper Connector B |  | 2-M7-STATOR.step  | Aluminum Alloy 5052 | 1 | CNC | |
| Gripper Slider Metal Bracket |  | 2-RAIL-BASE-1.step | Aluminum Alloy 5052 | 1 | CNC | Can be 3D printed in ABS with high infill, not recommended for long-term use |
| Slider to Gripper Extension |  | 2-SLIDER-FIX.step | Aluminum Alloy 5052 | 2 | CNC | |
| Rack |  | 2-RACK-1M.step | Aluminum Alloy 5052 | 2 | CNC | |

### 🧩 Machining Specifications
- Key dimension tolerance: ±0.02 mm GB/T1840-M
- Surface finish: Anodizing / Sandblasting
- Mating parts recommended: H7 / interference fit
---

## 🛒 Purchased Parts (Standard Parts)

> [!WARNING]
> Since everyone will need to assemble and tighten the screws themselves, standard hex socket screws have been selected. After prolonged operation, the screws may loosen, which will affect the precision of the robotic arm. For this reason, you are required to purchase additional hot melt glue to perform thread locking on the screws at each joint.

If you have a power drill or similar tools, you may choose to buy lock washers or thread-locking screws instead. However, **it is extremely important** that you use the lowest torque setting when using an electric screwdriver to avoid thread stripping, which will result in irreversible damage.

  | Name | Specification / Model | Quantity | Reference Price | Notes |
  |------|----------|------|----------|------|
  | Brushless motor | RobStride RS00 | 4 | 125 $/unit | [SeeedStudio](https://www.seeedstudio.com/Robostride-00-Actuator-p-6664.html) |
  | Brushless motor | RobStride RS06 | 3 | 210 $/unit |  [SeeedStudio](https://www.seeedstudio.com/Robostride-06-Actuator-p-6668.html)  |
  | CAN-USB driver board |  | 1 | 15 $/unit |   [SeeedStudio](https://www.amazon.com/Xiusiyt-Converter-Preloaded-PCAN-Firmware/dp/B0GBW7RTXD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)   |
  | XT30 2+2 Power Separation Borrd |  | 1 | 15 $/unit |   [SeeedStudio](https://www.seeedstudio.com/XT30-2-2-Power-Separation-Board-p-6707.html)   |
  | Bearing | 6803ZZ | 3 | 13 $/unit | [Amazong](https://www.amazon.com/uxcell-17x26x5mm-Shielded-Precision-Lubricated/dp/B0D54JSWBZ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) |
  | Bearing | AXK5578 | 1 | 12 $/unit | [Amazong](https://www.amazon.com/PZRT-AXK5578-Thrust-Bearings-Washers/dp/B0B3M3RZGW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) |
  | Linear rail | MGN9-170mm | 1 | 23 $/unit | [Amazong](https://www.amazon.com/uxcell-Sliding-Carriage-Bearing-Printers/dp/B0D54L45WM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) |
  | Slider block | MGN9 | 2 | 10 $/unit | [Amazong](https://www.amazon.com/uxcell-Bearing-Sliding-Carriage-Anti-Fall/dp/B0D9QBQDKB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) |
  | Gear | Module 1, boss type, 16 teeth, 6 mm bore | 1 | 44$/unit | [Amazong](https://www.amazon.com/Module-15-Teeth-Finished-Perforation/dp/B0GDSR1LKM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)  |
  | Silicone pad | 30x9x2mm | 1 | 10 $ | [Amazong](https://www.amazon.com/Self-Adhesive-Anti-Sliding-Anti-Scratch-Protectors-Appliances/dp/B0F9KVYXFZ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) |
  | Screw | KM3*7mm screw | 80+ |  |[Amazong](https://www.amazon.com/Uxcell-a16011300ux0872-M3x12mm-Carbon-Countersunk/dp/B01E6EIC2S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)   |
  | Screw | KM3*16mm screw | 8+ |  |[Amazong](https://www.amazon.com/Uxcell-a16011300ux0872-M3x12mm-Carbon-Countersunk/dp/B01E6EIC2S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)   |
  | Screw | KA3*12mm | 48+ |  | [Amazong](https://www.amazon.com/uxcell-Phillips-Tapping-Screws-Silver/dp/B01MXSS95N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)  |
  | Screw | HM3-8mm screw | 60+ |  | [Amazong](https://www.amazon.com/BNUOK-120pcs-Stainless-Threads-Spanner/dp/B0DJQG5YLF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)  |
  | Screw | HM3-30mm screw | 16+ |  | [Amazong](https://www.amazon.com/BNUOK-120pcs-Stainless-Threads-Spanner/dp/B0DJQFGRPQ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) 
  | Screw | HM4-8mm set screw | 6+ |  | [Amazong](https://www.amazon.com/iexcell-Partially-Threaded-Thread-Socket/dp/B0DR1NX178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)  |
  | Screw | HM4-16mm set screw | 18+ |  | [Amazong](https://www.amazon.com/iexcell-Partially-Threaded-Thread-Socket/dp/B0DR1NX178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)  |
  | Screw | HM4-70mm set screw | 4+ |  | [Amazong](https://www.amazon.com/iexcell-Partially-Threaded-Thread-Socket/dp/B0DR1NX178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)  |
 | Screw | HM3-6mm screw | 8+ |  | [Amazong](https://www.amazon.com/BNUOK-120pcs-Stainless-Threads-Spanner/dp/B0DJQG5YLF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)  |
 | Screw | HM3-26mm screw | 6+ |  | [Amazong](https://www.amazon.com/BNUOK-120pcs-Stainless-Threads-Spanner/dp/B0DJQG5YLF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)  |
 | XT30 2+2 Cable | Two Side Elbows 320mm | 1+ |   | This will require custom fabrication on your end.  |
 | XT30 2+2 Cable | Two Side Elbows 200mm | 4+ |   | This will require custom fabrication on your end.  |
 | XT30 2+2 Cable | One Side Elbow 300mm| 1+ |   |  This will require custom fabrication on your end. |
 | XT30 2+2 Cable | Two Side Straight | 1+ |  |   |
  | Screwdriver set | Hex key set | 1 | 16$  | [Amazong](https://www.amazon.com/Amazon-Basics-Ratcheting-Electronics-Screwdriver/dp/B07V4TFWFZ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)  |

### About Fixing
You may modify your base freely based on the 3D printed parts we provide. You can also use G-clamps according to the thickness of your desktop.

  | Name | Specification / Model | Quantity | Reference Price | Notes |
  |------|----------|------|----------|------|
  | Woodworking clamp | 6-inch G clamp | 2 | 20 $/unit | [Amazong](https://www.amazon.com/gp/aw/d/B092J1YW2M/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) |

### About Power Supply
The robotic arm is shipped without a power supply by default. You may connect your own battery, or purchase a reliable 48V 12.5A MeanWell power supply made in Taiwan. Additionally, you will need to buy a three-pin plug compliant with local standards and a wiring harness with XT30 female connector.

#### Consumables BOM

| Name | Specification | Qty | Reference Price | Notes | Image |
|:---|:---|:---:|:---:|:---|:---:|
| Power Supply | LRS-600-48（48V12.5A） | 1 | $69.5 | [amazon](https://www.amazon.com/LRS-600-48-Switching-Upgrade-Version-SE-600-48/dp/B0BV5XFYNS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) |  |
| Power Cord | US Standard AC Cable | 1 | $4.49 | [amazon](https://www.amazon.com/LIFEPOE-Power-3-3ft-Black-3-Prong/dp/B0FK4KPW2G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) |  |
| Output Port | XT60E Fixed Female Connector; XT60E Female + Lug - 10cm; 4mm Lug Hole | 1 | $9.99 | [amazon](https://www.amazon.com/LINSYRC-XT60E-F-Connector-Battery-Quadcopter/dp/B0CQK1P1DP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) |  |
| Power AC Wiring | 1.5mm²; Red, Blue, Yellow x1 each(User must crimp terminals to the wire — pre-crimped leads not included.); 10CM | 3 | $0.99 | [aliexpress](https://www.aliexpress.com/item/1005008648016252.html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) |  |
| 3-in-1 IEC Inlet Socket | Quick-connect type with red switch (Dual Nuts) | 1 | $1.98 | [aliexpress](https://www.aliexpress.com/item/1005005962021242.html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) |  |
| XT30 to XT60 adapter cable plug | XT30U female to XT60 male | 1 | 8.99$ | [amazon](https://www.amazon.com/dp/B0BY8PSHK6?th=1) |  |
| 304 Stainless Steel Phillips Countersunk Head Screw | M4x6 | 10 | $0.37 | / | / |
| 304 Stainless Steel Phillips Countersunk Head Screw | M3x8 | 2 | $0.36 | / | / |
| 304 Stainless Steel Phillips Pan Head Screw | M3x8 | 2 | $0.32 | / | / |
| Hex Nut | M3x2.5 | 2 | 2.10 CNY | / | / |

Printed Parts BOM:

| Name | Image | Quantity | Notes |
| --- | ---- | --- | ---- |
| [Front Shell](./3D_Printed_Parts/RS-power-Top%20Cover.stp) |  | 1 | PLA 0.4 nozzle, 0.2 layer height, 30% infill |
| [Rear Shell](./3D_Printed_Parts/RS-power-Bottom%20Cover.stp) |  | 1 | PLA 0.4 nozzle, 0.2 layer height, 30% infill |
| [Front Shell (Sliding Cover)](./3D_Printed_Parts/RS-power-Top%20Cover-Sliding%20Cover.stp) |  | 1 | PLA 0.4 nozzle, 0.2 layer height, 30% infill |
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

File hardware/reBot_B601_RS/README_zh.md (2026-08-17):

# 🤖 reBot DevArm 开源硬件规格说明

<p align="center">
  reBot-DevArm Banner
</p>
<p align="center">
  <strong>
    <a href="./README_zh.md">简体中文</a> &nbsp;|&nbsp;
    <a href="./README.md">English</a> &nbsp;|&nbsp;
    <a href="./README_fr.md">français</a>&nbsp;|&nbsp;
    <a href="./README_es.md">Español</a>
  </strong>
</p>

| 日期 | 版本 | 文件名 | 更新记录 |
| --- | ---- | --- | ---- |
| 2026-07-09 | v1.0 | reBot_B601_RS_v1.0_20260625.step | 首次上传 |

本 BOM 适用于 reBot Arm B601 RS 机械臂，该版本使用 ROBOSTRIDE 系列电机。另一个版本 reBot Arm B601 DM 使用 DAMIAO 电机；[请在此查看 BOM](../reBot_B601_DM/readme.md)。

# 📦 文件结构

* `3D_Printed_Parts/`：所有 3D 打印部件的 STEP 文件。
* `Metal_Parts/`：所有 CNC 加工金属部件的 STEP 文件。
* `Purchased_Parts/`：所有采购标准件的 STEP 文件。
* `reBot_B601_RS_v1.0_20260625.step`：完整机械臂装配文件。

# 🛒[获取所有零件](https://www.seeedstudio.com/reBot-Arm-B601-RS-Disassembly-Kit-Version-with-Power-Supply-Bundle.html)

* 我们提供五种套件选项：

  * **reBot-Arm-B601-RS-Disassembly-Kit**
  * **reBot-Arm-B601-RS-Assembly-Version**

# 📊 物料清单（BOM）

> [!WARNING]
> 声明：本次公开的 BOM **并不代表** Seeed 最终出货版本。本开源 v1.0 版本面向开发者以较低成本复现为目标，因此简化了一些非必要细节。
>
> Seeed 最终量产版本将包含用于防呆的金属激光雕刻；部分 3D 打印件会替换为金属件以提升耐用性；配合间隙和加工公差会根据工厂批量生产差异进行调整，以平衡精度和成本；同时还会增加定制线束，例如编织网保护等额外成本项。不过，机械结构本身保持一致。

---

## 🖨️ 3D 打印部件

| 部件描述 | 图片 | 文件名 | 材料 | 数量 | 备注 |
| --- | --- | --- | --- | -- | --- |
| 机械臂底座平台 |  | 1-BASE-PLATE.step | Bambu ABS 黑色 | 1  | 0.4 喷嘴，0.2 层高，30% 填充 |
| 机械臂底座连杆 |  | 1-RSM1-STATOR-1.step | Bambu ABS 黑色 | 1  | 0.4 喷嘴，0.2 层高，30% 填充 |
| 上臂左侧填充件 |  | 1-DOWN-DL.step | Bambu PLA 黑色与绿色 | 1  | 0.4 喷嘴，0.2 层高，15% 填充 |
| 上臂右侧填充件 |  | 1-DOWN-DR.step | Bambu PLA 黑色与绿色 | 1  | 0.4 喷嘴，0.2 层高，15% 填充 |
| 上臂与下臂中间填充件 |  | 1-SPACE-UP.step | Bambu ABS 黑色 | 2  | 0.4 喷嘴，0.2 层高，30% 填充 |
| 机械臂提手 |  | 1-HANDLE.step | Bambu ABS 黑色 | 1  | 0.4 喷嘴，0.2 层高，30% 填充 |
| 上臂与下臂盖板 |  | 1-COVER.step | Bambu PLA 绿色 | 2  | 0.4 喷嘴，0.2 层高，15% 填充 |
| 下臂左侧填充件 |  | 1-UP-DL.step | Bambu PLA 黑色与绿色 | 1  | 0.4 喷嘴，0.2 层高，15% 填充 |
| 下臂右侧填充件 |  | 1-UP-DR.step | Bambu PLA 黑色与绿色 | 1  | 0.4 喷嘴，0.2 层高，15% 填充 |
| 夹爪水平限位件 |  | 1-STOPPER-1.step | Bambu PLA 绿色 | 1  | 0.4 喷嘴，0.2 层高，15% 填充 |
| 夹爪滑轨支撑支架 |  | 1-RAIL-BASE-2.step | Bambu PLA 绿色 | 1  | 0.4 喷嘴，0.2 层高，15% 填充 |
| 夹爪手指 |  | 1-CLIP.step | Bambu ABS 黑色 | 2  | 0.4 喷嘴，0.2 层高，45% 填充。建议从夹爪侧面方向打印，以提升结构强度。 |

长时间拖拽线束 1 可能会磨损电机连接器，并导致电气接触不良。打印下表中的部件可以降低该风险。

| 部件描述 | 图片 | 文件名 | 材料 | 数量 | 备注 |
| --- | --- | --- | --- | -- | --- |
| 电机 1 两侧线束固定夹 |  | `RS_Motor1_wiring_harness_clip.stp` | Bambu Lab 黑色 ABS | 2  | 0.4 mm 喷嘴，0.2 mm 层高，30% 填充 |

### 🧩 打印建议

* 层高：0.2 mm
* 喷嘴：0.4 mm
* 支撑：根据需要添加
* 材料：高温和承重部件建议使用 ABS，填充率 30–80%；也可以使用尼龙或碳纤维增强材料。外观件建议使用 PLA，填充率 15%。
* 承重部件推荐材料：

---

## 🔩 CNC 加工金属部件

> [!WARNING]
> 部分可由 3D 打印替代的部件已在备注中说明，这可以显著降低成本。

| 部件描述 | 图片 | 文件名 | 材料 | 数量 | 加工方式 | 备注 |
| --- | --- | --- | --- | -- | ---- | --- |
| 电机 1 轴承安装座 |  | 2-RSM1-ROTOR-1.step | 5052 铝合金 | 1  | CNC  | |
| Link1 左侧金属件  |  | 2-RSM-ROTOR-L.step | 5052 铝合金 | 1  | CNC  | |
| Link1 右侧金属件  |  | 2-RSM-ROTOR-R.step | 5052 铝合金 | 4  | CNC  | |
| Link1 底部金属件  |  | 2-RSM1-ROTOR-1.step | 5052 铝合金 | 3  | CNC  | |
| 关节金属圆盘 |  | 2-CD.step | 5052 铝合金 | 3  | CNC  | 用于遮挡螺丝 |
| RS06 前侧延长件 |  | 2-RSM2-STATOR-1.step  | 5052 铝合金 | 2  | CNC  | |
| RS06 后侧延长件 |  | 2-RSM2-STATOR-2.step  | 5052 铝合金 | 2  | CNC  | |
| Link2 左右金属件  |  | 2-LINK-2_3.step | 5052 铝合金 | 2  | CNC  | |
| 上限位 L |  | 2-Upper-Limit_L.stp | 5052 铝合金 | 1  | CNC  | |
| 上限位 R |  | 2-Upper-Limit_R.stp | 5052 铝合金 | 1  | CNC  | |
| 下臂与上臂连接件 L |  | 2-RSM3-ROTATOR-L.step | 5052 铝合金 | 1  | CNC  | |
| 下臂与上臂连接件 R |  | 2-RSM3-ROTATOR-R.step | 5052 铝合金 | 1  | CNC  | |
| Link3 左侧金属件  |  | 2-LINK-3_4-L.step | 5052 铝合金 | 1  | CNC  | |
| Link3 右侧金属件  |  | 2-LINK-3_4-R.step | 5052 铝合金 | 1  | CNC  | |
| Link3 左右连接件  |  | 2-SPACE-UP-2.step | 5052 铝合金 | 1  | CNC  | |
| 电机 4–7 线缆固定件 |  | 1-O-CLIP.step | 5052 铝合金 | 4  | CNC  | Seeed Studio 出货版本中，该部件会作为一个与其他部件集成的 CNC 金属件生产，因此制造成本较高。如果自行复现硬件，可以使用 ABS 材料 3D 打印该部件，并在红色箭头标记的位置安装 M2 螺母。 |
| 电机4背部轴承座 |  | 2-Motor_Back_Spacer.step |  5052 铝合金  | 1 | CNC |  |
| Link4-5_L |  | 2-LINK-4_5-L.step | 5052 铝合金 | 1  | CNC  | |
| Link4-5_R |  | 2-LINK-4_5-R.step | 5052 铝合金 | 1  | CNC  | |
| Link5 |  | 2-RSM5-STATOR.step | 5052 铝合金 | 1  | CNC  | |
| 手腕连接件 A |  | 2-RSM6-RORATOR-1.step | 5052 铝合金 | 1  | CNC  | |
| 手腕连接件 B |  | 2-RSM6-RORATOR-2.step | 5052 铝合金 | 1  | CNC  | |
| 夹爪连接件 A |  | 2-M6-ROTOR.step | 5052 铝合金 | 1  | CNC  | |
| 夹爪连接件 B |  | 2-M7-STATOR.step | 5052 铝合金 | 1  | CNC  | |
| 夹爪滑块金属支架 |  | 2-RAIL-BASE-1.step | 5052 铝合金 | 1  | CNC  | 可使用高填充率 ABS 进行 3D 打印，但不建议长期使用 |
| 滑块到夹爪延长件 |  | 2-SLIDER-FIX.step | 5052 铝合金 | 2  | CNC  | |
| 齿条 |  | 2-RACK-1M.step | 5052 铝合金 | 2  | CNC  | |

### 🧩 加工规格

* 关键尺寸公差：±0.02 mm，GB/T1840-M
* 表面处理：阳极氧化 / 喷砂
* 推荐配合方式：H7 / 过盈配合

---

## 🛒 采购件（标准件）

> [!WARNING]
> 由于用户需要自行组装并拧紧螺丝，因此本 BOM 选择了标准内六角螺丝。长时间运行后，螺丝可能会松动，从而影响机械臂精度。因此，建议额外购买热熔胶，用于对各关节处螺丝进行螺纹锁固。
>
> 如果你有电钻或类似工具，也可以选择购买弹簧垫圈或防松螺丝。不过，使用电动螺丝刀时 **务必使用最低扭矩档位**，避免滑牙，否则可能造成不可逆损坏。

| 名称 | 规格 / 型号 | 数量  | 参考价格 | 备注 |
| --- | --- | --- | --- | --- |
| 无刷电机 | RobStride RS00 | 4 | 125 美元/个 | [SeeedStudio](https://www.seeedstudio.com/Robostride-00-Actuator-p-6664.html) |
| 无刷电机 | RobStride RS06 | 3 | 210 美元/个 | [SeeedStudio](https://www.seeedstudio.com/Robostride-06-Actuator-p-6668.html) |
| CAN-USB 驱动板 | | 1 | 15 美元/个 | [SeeedStudio](https://www.amazon.com/Xiusiyt-Converter-Preloaded-PCAN-Firmware/dp/B0GBW7RTXD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) |
| XT30 2+2 电源分配板 | | 1 | 15 美元/个 | [SeeedStudio](https://www.seeedstudio.com/XT30-2-2-Power-Separation-Board-p-6707.html) |
| 轴承 | 6803ZZ | 3 | 13 美元/个 | [Amazon](https://www.amazon.com/uxcell-17x26x5mm-Shielded-Precision-Lubricated/dp/B0D54JSWBZ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) |
| 轴承 | AXK5578 | 1 | 12 美元/个 | [Amazon](https://www.amazon.com/PZRT-AXK5578-Thrust-Bearings-Washers/dp/B0B3M3RZGW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) |
| 直线导轨 | MGN9-170mm | 1 | 23 美元/个 | [Amazon](https://www.amazon.com/uxcell-Sliding-Carriage-Bearing-Printers/dp/B0D54L45WM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) |
| 滑块 | MGN9 | 2 | 10 美元/个 | [Amazon](https://www.amazon.com/uxcell-Bearing-Sliding-Carriage-Anti-Fall/dp/B0D9QBQDKB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) |
| 齿轮 | 模数 1，带轮毂，16 齿，6 mm 孔径 | 1 | 44 美元/个 | [Amazon](https://www.amazon.com/Module-15-Teeth-Finished-Perforation/dp/B0GDSR1LKM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) |
| 硅胶垫 | 30x9x2mm | 1 | 10 美元 | [Amazon](https://www.amazon.com/Self-Adhesive-Anti-Sliding-Anti-Scratch-Protectors-Appliances/dp/B0F9KVYXFZ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) |
| 螺丝 | KM3*7mm 螺丝 | 80+ | | [Amazon](https://www.amazon.com/Uxcell-a16011300ux0872-M3x12mm-Carbon-Countersunk/dp/B01E6EIC2S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) |
| 螺丝 | KM3*16mm 螺丝 | 8+  | | [Amazon](https://www.amazon.com/Uxcell-a16011300ux0872-M3x12mm-Carbon-Countersunk/dp/B01E6EIC2S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) |
| 螺丝 | KA3*12mm | 48+ | | [Amazon](https://www.amazon.com/uxcell-Phillips-Tapping-Screws-Silver/dp/B01MXSS95N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) |
| 螺丝 | HM3-8mm 螺丝 | 60+ | | [Amazon](https://www.amazon.com/BNUOK-120pcs-Stainless-Threads-Spanner/dp/B0DJQG5YLF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) |
| 螺丝 | HM3-30mm 螺丝 | 16+ | | [Amazon](https://www.amazon.com/BNUOK-120pcs-Stainless-Threads-Spanner/dp/B0DJQFGRPQ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) |
| 螺丝 | HM4-8mm 紧定螺丝 | 6+  | | [Amazon](https://www.amazon.com/iexcell-Partially-Threaded-Thread-Socket/dp/B0DR1NX178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) |
| 螺丝 | HM4-16mm 紧定螺丝 | 18+ | | [Amazon](https://www.amazon.com/iexcell-Partially-Threaded-Thread-Socket/dp/B0DR1NX178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) |
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

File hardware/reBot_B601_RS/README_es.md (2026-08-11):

# 🤖 Especificación del hardware de código abierto de reBot DevArm

<p align="center">
  Banner de reBot-DevArm
</p>
<p align="center">
  <strong>
    <a href="./README_zh.md">简体中文</a> &nbsp;|&nbsp;
    <a href="./README.md">English</a> &nbsp;|&nbsp;
    <a href="./README_fr.md">français</a>&nbsp;|&nbsp;
    <a href="./README_es.md">Español</a>
  </strong>
</p>

| Fecha | Versión | Nombre del fichero | Registro de cambios |
|---|---|---|---|
|  2026-07-09 | v1.0 |  reBot_B601_RS_v1.0_20260625.step  | Publicación inicial |

Esta BOM corresponde al brazo robótico reBot Arm B601 RS, que utiliza motores de la serie RobStride. La otra versión, reBot Arm B601 DM, utiliza motores DAMIAO; [consulta la BOM aquí](../reBot_B601_DM/readme.md).

# 📦 Estructura de ficheros
*   3D_Printed_Parts/: ficheros STEP de todas las piezas impresas en 3D.
*   Metal_Parts/: ficheros STEP de todas las piezas metálicas mecanizadas por CNC.
*   Purchased_Parts/: ficheros STEP de todos los componentes comprados.
*   reBot_B601_RS_v1.0_20260625.step: fichero de ensamblaje completo del brazo robótico.

# 🛒 [Consigue todas las piezas](https://www.seeedstudio.com/reBot-Arm-B601-RS-Disassembly-Kit-Version-with-Power-Supply-Bundle.html)
- Ofrecemos cinco opciones de kit:
  - **reBot-Arm-B601-RS-Disassembly-Kit**
  - **reBot-Arm-B601-RS-Assembly-Version**

# 📊 Lista de materiales (BOM)

> [!WARNING]
> Aviso: la BOM publicada **no** representa la versión final que envía Seeed. Esta versión de código abierto v1.0 está optimizada para que los desarrolladores puedan reproducirla con el mínimo coste, con algunos detalles no esenciales simplificados.
> La versión final de producción de Seeed incluirá grabado láser en las piezas metálicas como sistema antierrores, algunas piezas impresas en 3D se sustituirán por metal para mayor durabilidad, las holguras y tolerancias de mecanizado se ajustarán en función de la variación de fábrica (equilibrando precisión y coste) y se añadirá cableado a medida (p. ej., protección con funda trenzada) con coste adicional. No obstante, la estructura mecánica sigue siendo idéntica.

---

## 🖨️ Piezas impresas en 3D

| Descripción de la pieza | Imagen | Nombre del fichero | Material | Cant. | Notas |
|---|---|---|---|---|---|
| Plataforma de la base del brazo robótico |  | 1-BASE-PLATE.step | Bambu ABS negro | 1 | boquilla 0.4, altura de capa 0.2, relleno 30% |
| Eslabón de la base del brazo robótico |  | 1-RSM1-STATOR-1.step | Bambu ABS negro | 1 | boquilla 0.4, altura de capa 0.2, relleno 30% |
| Relleno izquierdo del brazo superior |  | 1-DOWN-DL.step | Bambu PLA negro y verde | 1 | boquilla 0.4, altura de capa 0.2, relleno 15% |
| Relleno derecho del brazo superior |  | 1-DOWN-DR.step | Bambu PLA negro y verde | 1 | boquilla 0.4, altura de capa 0.2, relleno 15% |
| Relleno central del brazo superior y del antebrazo |  | 1-SPACE-UP.step | Bambu ABS negro | 2 | boquilla 0.4, altura de capa 0.2, relleno 30% |
| Asa del brazo |  | 1-HANDLE.step | Bambu ABS negro | 1 | boquilla 0.4, altura de capa 0.2, relleno 30% |
| Cubierta del brazo superior y del antebrazo |  | 1-COVER.step | Bambu PLA verde | 2 | boquilla 0.4, altura de capa 0.2, relleno 15% |
| Relleno izquierdo del antebrazo |  | 1-UP-DL.step | Bambu PLA negro y verde | 1 | boquilla 0.4, altura de capa 0.2, relleno 15% |
| Relleno derecho del antebrazo |  | 1-UP-DR.step | Bambu PLA negro y verde | 1 | boquilla 0.4, altura de capa 0.2, relleno 15% |
| Tope horizontal de la pinza (gripper) |  | 1-STOPPER-1.step | Bambu PLA verde | 1 | boquilla 0.4, altura de capa 0.2, relleno 15% |
| Soporte del deslizador de la pinza |  | 1-RAIL-BASE-2.step | Bambu PLA verde | 1 | boquilla 0.4, altura de capa 0.2, relleno 15% |
| Dedo de la pinza |  | 1-CLIP.step | Bambu ABS negro | 2 | boquilla 0.4, altura de capa 0.2, relleno 45%. Imprímelo apoyado sobre el lateral de la pinza para mejorar su resistencia estructural. |

El arrastre prolongado del arnés de cableado del motor 1 puede desgastar el conector del motor y provocar un mal contacto eléctrico. Imprimir las piezas que se indican a continuación puede mitigar este riesgo.

| Descripción de la pieza | Imagen | Nombre del fichero | Material | Cant. | Notas |
| ---- | ---- | ---- | ---- | ---- | ---- |
| Clips de arnés de cableado para ambos lados del motor 1 |  | `RS_Motor1_wiring_harness_clip.stp` | ABS negro Bambu Lab | 2 | boquilla de 0.4 mm, altura de capa 0.2 mm, relleno 30% |

### 🧩 Recomendaciones de impresión
- Altura de capa: 0.2 mm
- Boquilla: 0.4 mm
- Soportes: añadir según sea necesario
- Materiales: las piezas sometidas a altas temperaturas y a carga utilizan ABS con un relleno del 30–80%; también puede usarse nailon o materiales reforzados con fibra de carbono. Las piezas estéticas utilizan PLA con un relleno del 15%.

---

## 🔩 Piezas metálicas mecanizadas por CNC

> [!WARNING]
> Algunas piezas que pueden sustituirse por impresión 3D se indican en las notas, lo que puede reducir considerablemente los costes.
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

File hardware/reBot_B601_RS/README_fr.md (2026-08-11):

# 🤖 Spécification matérielle open source du reBot DevArm

<p align="center">
  Bannière reBot-DevArm
</p>
<p align="center">
  <strong>
    <a href="./README_zh.md">简体中文</a> &nbsp;|&nbsp;
    <a href="./README.md">English</a> &nbsp;|&nbsp;
    <a href="./README_fr.md">français</a>&nbsp;|&nbsp;
    <a href="./README_es.md">Español</a>
  </strong>
</p>

| Date | Version | Nom du fichier | Journal des modifications |
| --- | --- | --- | --- |
| 2026-07-09 | v1.0 | reBot_B601_RS_v1.0_20260625.step | Première mise en ligne |

Cette BOM concerne le bras robotique reBot Arm B601 RS, qui utilise des moteurs de la série ROBOSTRIDE. L’autre version, reBot Arm B601 DM, utilise des moteurs DAMIAO ; [voir la BOM ici](../reBot_B601_DM/readme.md).

# 📦 Structure des fichiers

* `3D_Printed_Parts/` : fichiers STEP de toutes les pièces imprimées en 3D.
* `Metal_Parts/` : fichiers STEP de toutes les pièces métalliques usinées CNC.
* `Purchased_Parts/` : fichiers STEP de tous les composants achetés.
* `reBot_B601_RS_v1.0_20260625.step` : fichier d’assemblage complet du bras robotique.

# 🛒[Obtenir toutes les pièces](https://www.seeedstudio.com/reBot-Arm-B601-RS-Disassembly-Kit-Version-with-Power-Supply-Bundle.html)

* Nous proposons cinq options de kits :

  * **reBot-Arm-B601-RS-Disassembly-Kit**
  * **reBot-Arm-B601-RS-Assembly-Version**

# 📊 Nomenclature — Bill of Materials (BOM)

> [!WARNING]
> Déclaration : la BOM publiée **ne représente pas** la version finale expédiée par Seeed. Cette version open source v1.0 est optimisée pour permettre aux développeurs de la reproduire à moindre coût, avec certains détails non essentiels simplifiés.
>
> La version finale de production Seeed inclura une gravure laser sur les pièces métalliques pour faciliter l’assemblage et éviter les erreurs, certaines pièces imprimées en 3D seront remplacées par des pièces métalliques pour améliorer la durabilité, les jeux et tolérances d’usinage seront ajustés en fonction des variations de fabrication en usine, et un câblage personnalisé, par exemple avec gaine tressée de protection, sera ajouté moyennant un coût supplémentaire. Cependant, la structure mécanique reste identique.

---

## 🖨️ Pièces imprimées en 3D
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

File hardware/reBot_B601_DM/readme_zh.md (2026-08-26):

# 🤖 reBot DevArm 开源硬件说明

<p align="center">
  reBot-DevArm Banner
</p>
<p align="center">
  <strong>
    <a href="./readme_zh.md">简体中文</a> &nbsp;|&nbsp;
    <a href="./readme.md">English</a> &nbsp;|&nbsp;
    <a href="./readme_jp.md">日本語</a>&nbsp;|&nbsp;
    <a href="./readme_fr.md">français</a>&nbsp;|&nbsp;
    <a href="./readme_es.md">Español</a>
  </strong>
</p>

|  日期 | 版本号 | 文件名 | 更新日志 |
|---|---|---|---|
|  3.31.2026 | v1.0 |  reBot_B601_DM_v1.0_20260331.step  | 第一次上传 |
|  4.25.2026 | v1.1 |  reBot_B601_DM_v1.1_20260425.step  | 增加了末端3个关节电机的线束卡口`Cable Restraint`，防松防脱落。修复了第一个关节型号`由4310改为4340P`。底部增加了CNC件`02_Base_Reinforcement_Part.step`加强底部强度。增加了线束卡扣。 |

当前BOM为reBot Arm B601 DM机械臂清单，所使用的是Damiao43系列电机，另一款reBot Arm B601 RS机械臂所使用的是RobStride电机，[清单请看这里](../reBot_B601_RS/README.md)

# 📦 文件结构
*   `3D_Printed_Parts/`: 所有3D打印文件的Step。
*   `Metal_Parts/`: 所有金属加工文件的Step。
*   `Purchased_Parts/`: 所有购买件的Step。
*   `reBot_B601_DM_v1.1_20260415step`: 机械臂整体装配文件。

# 📊 物料清单（BOM）

> [!WARNING]
>特此申明，公布的BOM并非代表Seeed出货的最终版本，此`v1.1`开源版本是方便开发者并能够尽可能减少成本自己加工复现的版本,减少了一些不必要的细节开支，Seeed 最终出货版本会有金属镭雕防呆提示，部分3D打印件为了耐久会替换为金属件，根据金属加工厂的误差做间隙和加工精度调整（精度和成本的平衡），线束的特殊定制（例如增加编制绳保护）等需要增加一定成本的细节优化，但是结构构型相同。

---

## 🖨️ 3D打印件
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

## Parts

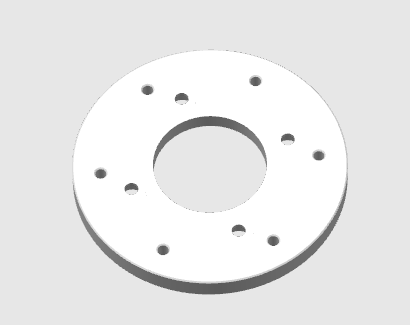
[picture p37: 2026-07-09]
hardware/reBot_B601_RS/Metal_Parts/images/Motor4_Back_Extension.png

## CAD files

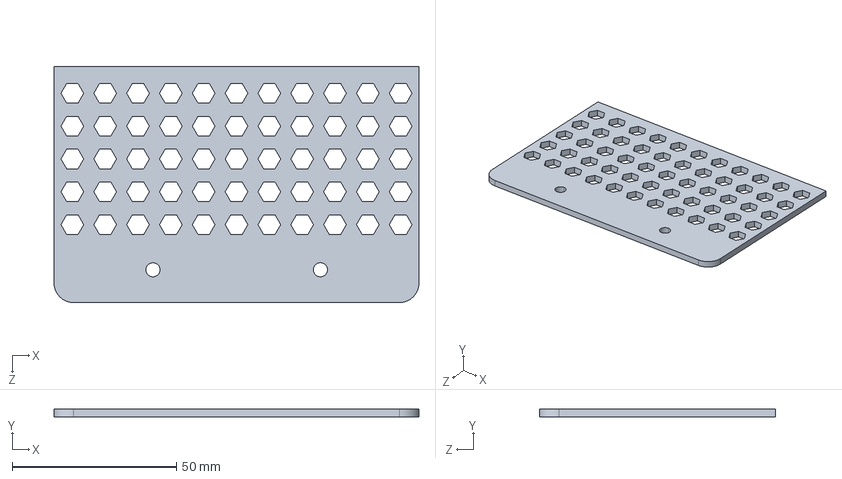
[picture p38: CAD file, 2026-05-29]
hardware/reBot_B601_DM/3D_Printed_Parts/DM-power-Top Cover-Sliding Cover.STEP
111.2 x 2.45 x 71.9 mm

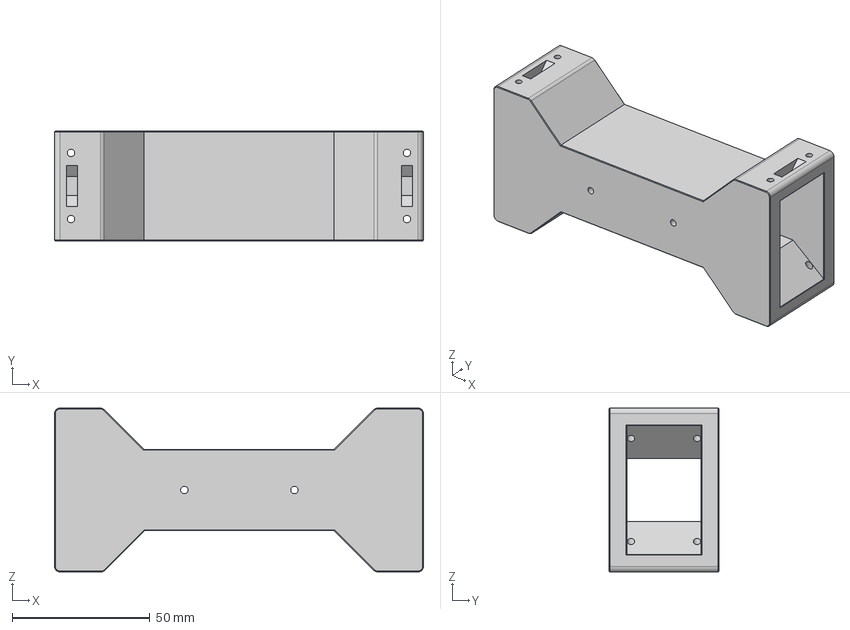
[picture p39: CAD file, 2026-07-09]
hardware/reBot_B601_RS/3D_Printed_Parts/1-SPACE-UP.step
134.0 x 40.0 x 59.5 mm

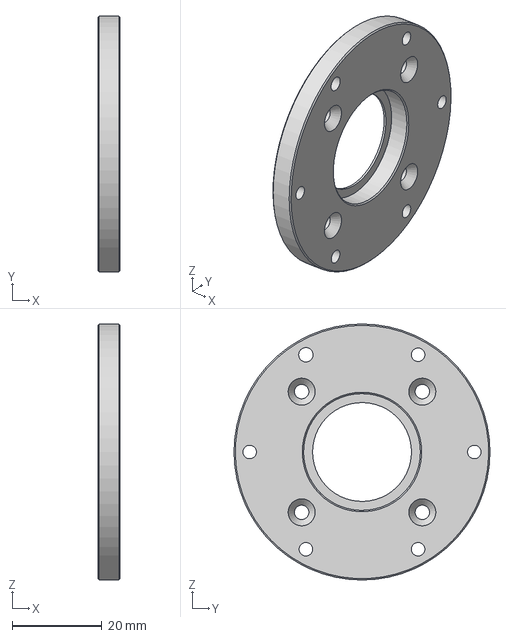
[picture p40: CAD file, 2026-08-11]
hardware/reBot_B601_RS/Metal_Parts/2-Motor_Back_Spacer.step
5.00 x 57.0 x 57.0 mm

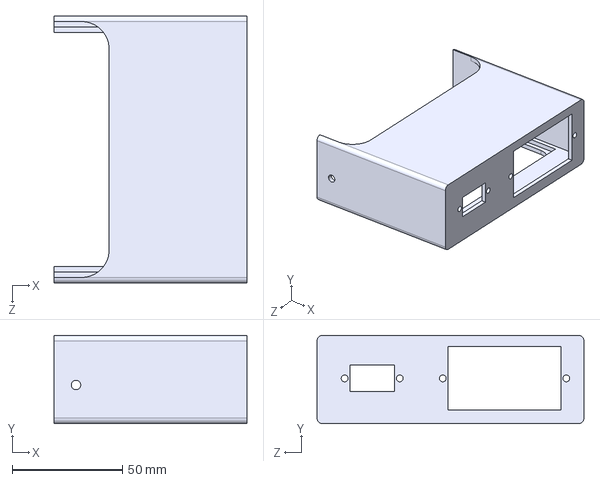
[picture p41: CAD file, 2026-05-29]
hardware/reBot_B601_DM/3D_Printed_Parts/DM-power-Top Cover.STEP
87.5 x 40.0 x 121.0 mm

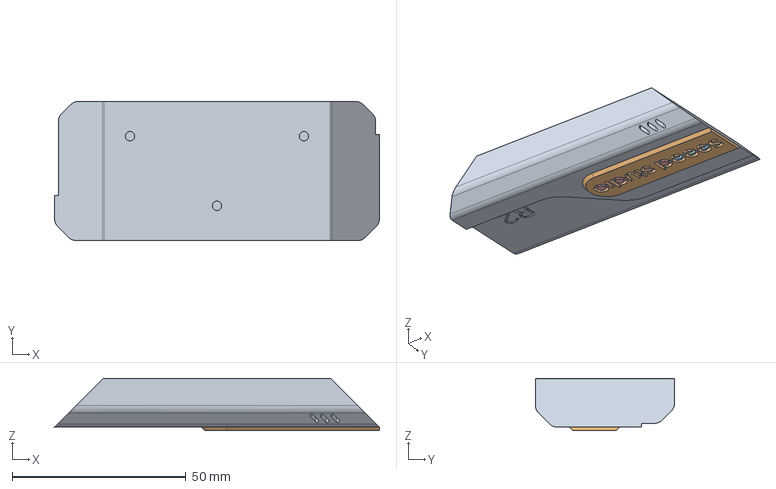
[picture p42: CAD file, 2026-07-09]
hardware/reBot_B601_RS/3D_Printed_Parts/1-UP-DR.step
93.4 x 40.0 x 15.0 mm

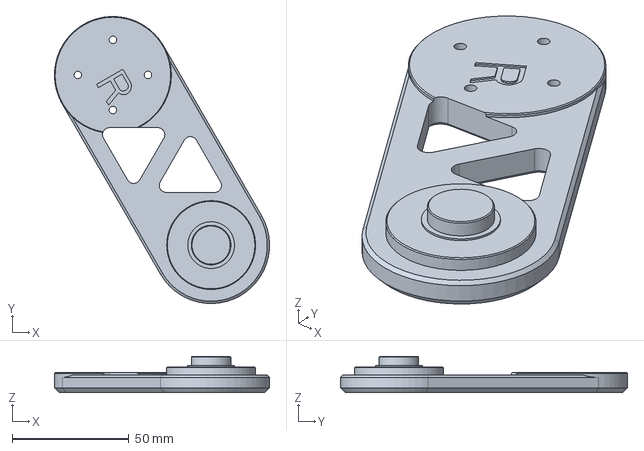
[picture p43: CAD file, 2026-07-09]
hardware/reBot_B601_RS/Metal_Parts/2-RSM3-ROTATOR-R.step
92.0 x 122.7 x 15.5 mm

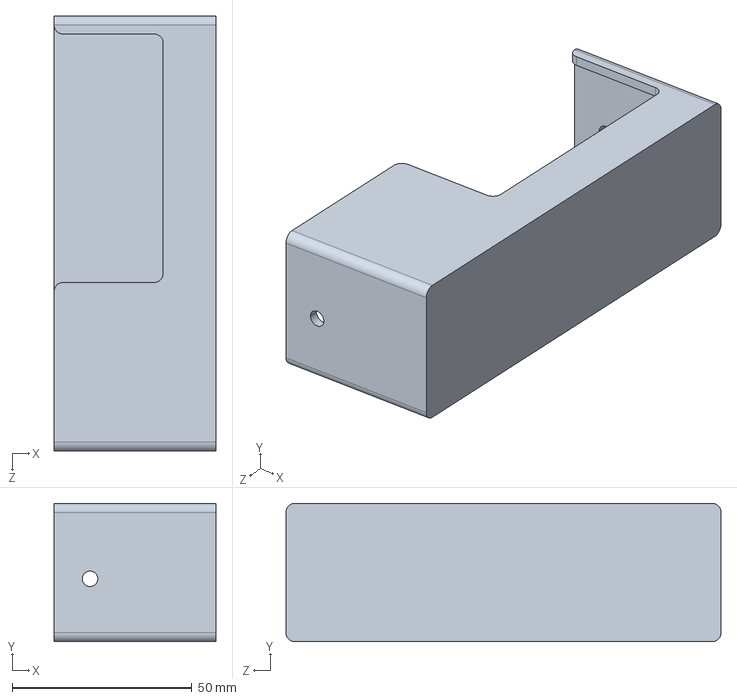
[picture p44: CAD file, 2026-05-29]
hardware/reBot_B601_DM/3D_Printed_Parts/DM-power-Bottom Cover.STEP
45.0 x 38.5 x 121.0 mm

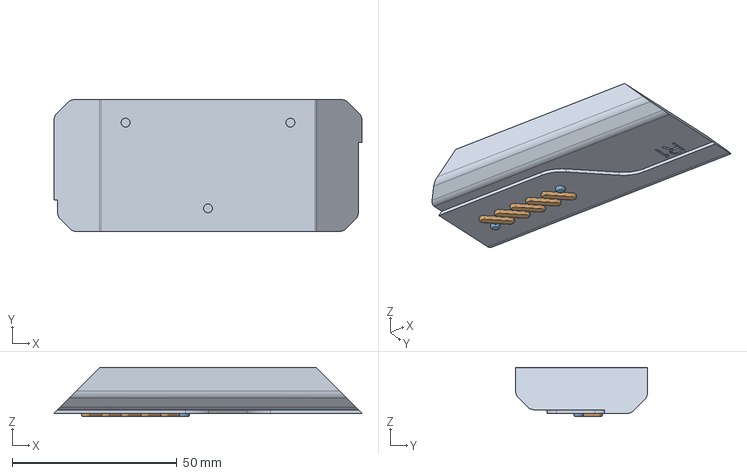
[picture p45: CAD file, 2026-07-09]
hardware/reBot_B601_RS/3D_Printed_Parts/1-DOWN-DR.step
93.4 x 40.0 x 15.0 mm

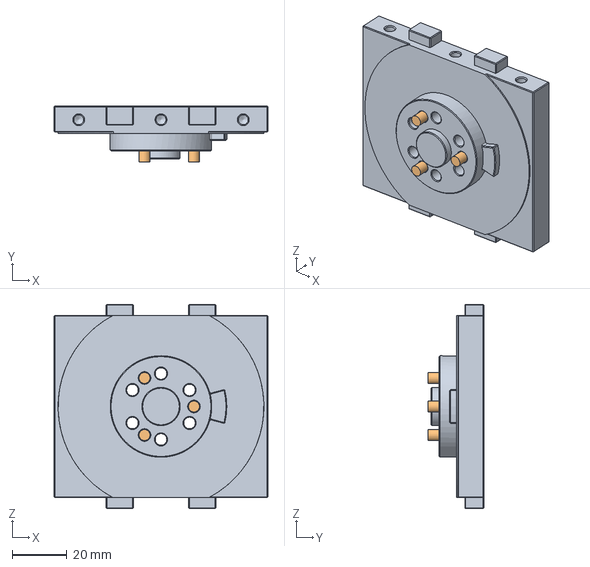
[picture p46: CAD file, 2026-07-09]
hardware/reBot_B601_RS/Metal_Parts/2-RSM1-ROTOR-1.step
78.0 x 20.4 x 74.5 mm

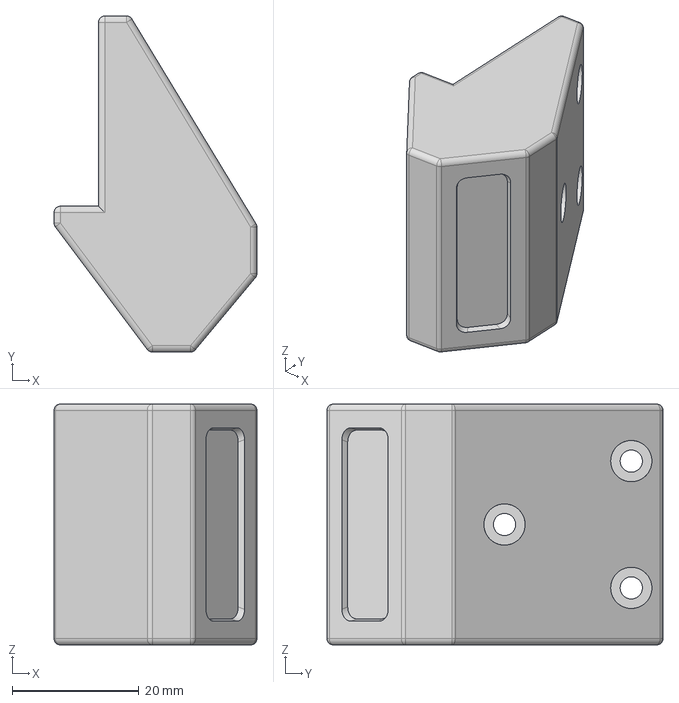
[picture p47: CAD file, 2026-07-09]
hardware/reBot_B601_RS/3D_Printed_Parts/1-STOPPER-1.step
32.0 x 53.0 x 38.0 mm

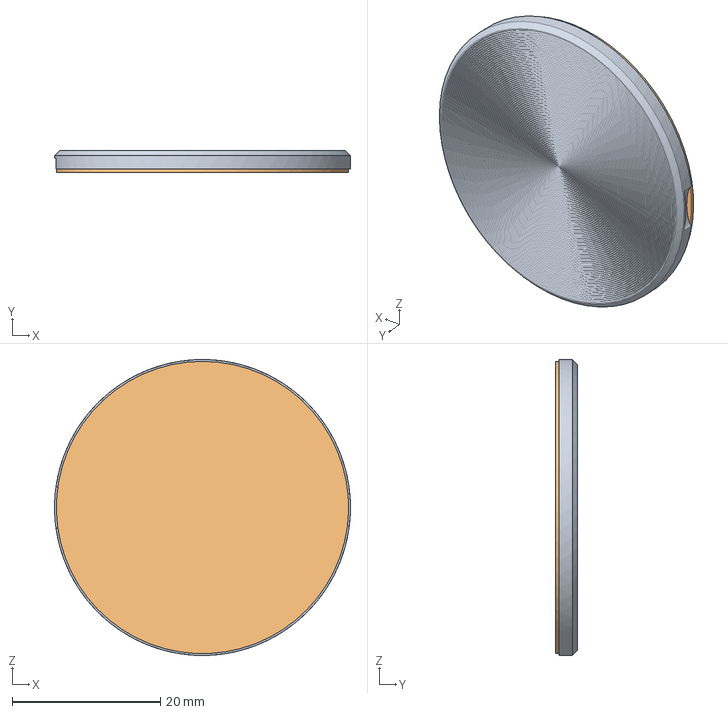
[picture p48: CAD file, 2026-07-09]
hardware/reBot_B601_RS/Metal_Parts/2-CD.step
40.0 x 3.00 x 40.0 mm

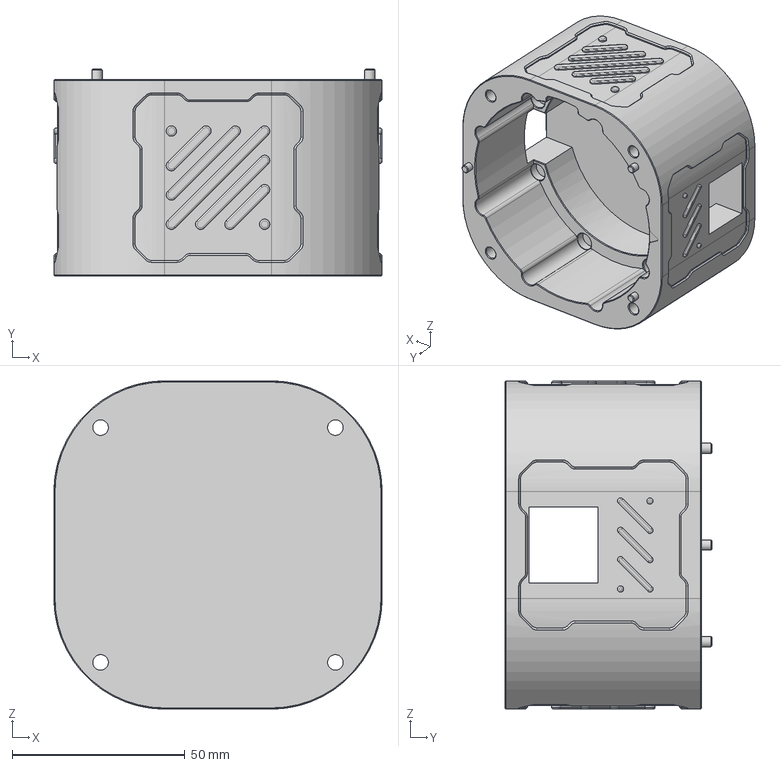
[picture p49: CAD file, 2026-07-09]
hardware/reBot_B601_RS/3D_Printed_Parts/1-RSM1-STATOR-1.step
95.0 x 60.0 x 95.0 mm

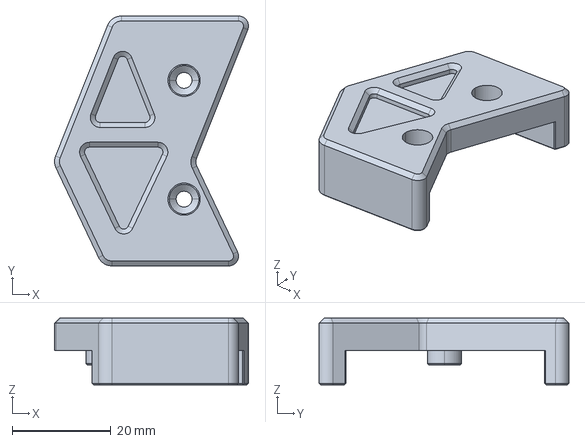
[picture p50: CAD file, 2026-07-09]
hardware/reBot_B601_RS/Metal_Parts/2-Upper-Limit_L.stp
39.2 x 50.5 x 13.5 mm

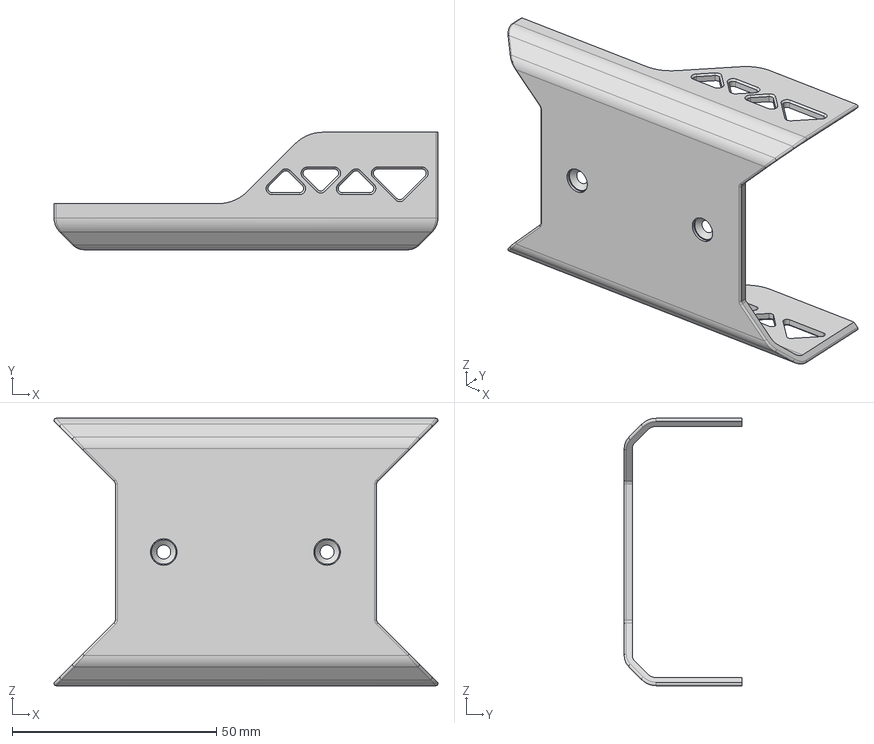
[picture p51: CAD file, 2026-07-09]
hardware/reBot_B601_RS/3D_Printed_Parts/1-COVER.step
94.0 x 28.8 x 65.5 mm

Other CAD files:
hardware/reBot_B601_RS/Metal_Parts/2-LINK-3_4-L.step
hardware/reBot_B601_RS/3D_Printed_Parts/1-HANDLE.step
hardware/reBot_B601_RS/Metal_Parts/2-RSM2-STATOR-1.step
hardware/reBot_B601_RS/3D_Printed_Parts/1-DOWN-DL.step
hardware/reBot_B601_RS/3D_Printed_Parts/1-BASE-PLATE.step
hardware/reBot_B601_RS/3D_Printed_Parts/1-CLIP.step
hardware/reBot_B601_RS/3D_Printed_Parts/1-RAIL-BASE-2.step
hardware/reBot_B601_RS/3D_Printed_Parts/1-UP-DL.step
hardware/reBot_B601_RS/3D_Printed_Parts/RS_Motor1_wiring_harness_clip.stp
hardware/reBot_B601_RS/Metal_Parts/1-O-CLIP.step
hardware/reBot_B601_RS/Metal_Parts/2-LINK-2_3.step
hardware/reBot_B601_RS/Metal_Parts/2-LINK-3_4-R.step
hardware/reBot_B601_RS/Metal_Parts/2-LINK-4_5-L.step
hardware/reBot_B601_RS/Metal_Parts/2-LINK-4_5-R.step
hardware/reBot_B601_RS/Metal_Parts/2-M6-ROTOR.step
hardware/reBot_B601_RS/Metal_Parts/2-M7-ROTOR.step
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

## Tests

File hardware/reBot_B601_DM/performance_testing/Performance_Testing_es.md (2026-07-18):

# 🧪 Referencia de pruebas de rendimiento del reBot-DevArm en el robot real

<p align="center">
  Cabecera de reBot-DevArm
</p>

<p align="center">
  <strong>
    <a href="./Performance_Testing_zh.md">简体中文</a> &nbsp;|&nbsp;
    <a href="./Performance_Testing.md">English</a> &nbsp;|&nbsp;
    <a href="./Performance_Testing_JP.md">日本語</a>&nbsp;|&nbsp;
    <a href="./Performance_Testing_Fr.md">français</a>&nbsp;|&nbsp;
    <a href="./Performance_Testing_es.md">Español</a>
  </strong>
</p>

> [!NOTE]
> Este documento proporciona datos de referencia de pruebas de rendimiento para el reBot Arm B601-DM en condiciones de trabajo normales y extremas.

> [!WARNING]
> **Aviso de versión**: Esta prueba se basa en el reBot Arm B601-DM equipado con **motores Damiao V4**. El rendimiento de las versiones V3 y anteriores es diferente. Los datos son solo orientativos; verifica el rendimiento con tus propias pruebas.

---

## 📋 Índice

- [⚡ Prueba de rendimiento en condiciones extremas](#-prueba-de-rendimiento-en-condiciones-extremas)
- [📈 Curva de carga oficial](#-curva-de-carga-oficial)
- [📝 Conclusiones y recomendaciones](#-conclusiones-y-recomendaciones)
- [🙋 Preguntas frecuentes (FAQ)](#-preguntas-frecuentes-faq)
- [📅 Registro de actualizaciones](#-registro-de-actualizaciones)
- [📞 Soporte técnico](#-soporte-técnico)

---

## ⚡ Prueba de rendimiento en condiciones extremas

### Condiciones de prueba

**Prueba de movimiento dinámico**:
- Duración de cada movimiento: 5 s
- Tipo de movimiento: vaivén
- Extensión del brazo en la prueba: 5 %–70 % / 5 %–100 % del alcance nominal

**Prueba de mantenimiento estático**:
- Postura de prueba: mantenimiento estático de la carga
- Extensión del brazo en la prueba: 70 % / 100 % del alcance nominal

### Resultados de la prueba

> 👉 **Conclusión clave**: La estructura mecánica es suficientemente resistente. La finalización de la prueba se debió a la **protección por sobrecalentamiento del motor n.º 2**. Se recomienda una carga de trabajo **≤ 1.5 kg**, una extensión de trabajo **< 70 % del alcance nominal** y el uso de refrigeración activa.

#### 1. Prueba de movimiento dinámico

| Extensión del brazo | Carga | Duración | Motivo de finalización |
|---|---|---|---|
| Vaivén 5 %–70 % | 1.5 kg | > 2 h | El motor n.º 2 alcanzó 90 °C; detención manual |
| Vaivén 5 %–70 % | 2.5 kg | 40 min | Se activó la protección por sobrecalentamiento |
| Vaivén 5 %–100 % | 1.5 kg | 45 min | Se activó la protección por sobrecalentamiento |

#### 2. Prueba de mantenimiento estático

| Posición | Carga (kg) | Duración máxima | Motivo de finalización |
|---|---|---|---|
| Mantenimiento con extensión al 70 % | 1.5 | 18 min | Protección por sobrecalentamiento |
| Mantenimiento con extensión al 100 % | 1.5 | 3 min | Protección por sobrecalentamiento |

---

## 📈 Curva de carga oficial

Curva de carga de 12 N·m

<p align="center">Curva de carga de 12 N·m del motor Damiao serie 43</p>

---

## 📝 Conclusiones y recomendaciones

### Recomendaciones de uso

1. **Condiciones de trabajo recomendadas**
   - Carga: ≤ 1.5 kg
   - Extensión de trabajo: < 70 % del alcance nominal (450 mm)
   - Velocidad: < 70 % de la velocidad máxima
   - Temperatura ambiente: de 15 °C a 35 °C

2. **Recomendaciones de refrigeración**
   - Añadir refrigeración activa durante trabajos prolongados con alta carga
   - Después de 2 horas de funcionamiento continuo, dejar reposar 10-15 minutos
   - Evitar la exposición directa al sol y los espacios cerrados

---

## 🙋 Preguntas frecuentes (FAQ)

<details>
<summary><b>P1: ¿El rendimiento disminuye en entornos de alta temperatura?</b></summary>

Sí. Cuando la temperatura ambiente supera los 35 °C o la temperatura del motor supera los 75 °C, se recomienda reducir la carga y la velocidad para preservar la precisión y prolongar la vida útil.

</details>

<details>
<summary><b>P2: ¿Estos datos se aplican a todas las versiones?</b></summary>

Esta prueba se basa en la versión con **motores Damiao V4**. El rendimiento de las versiones V3 y anteriores es diferente.

</details>

---

## 📅 Registro de actualizaciones

| Versión | Fecha | Cambios | Autor |
|---|---|---|---|
| v1.0 | 01/04/2026 | Versión inicial con datos básicos de pruebas de rendimiento | Equipo AI Robotics de SeeedStudio |

---

## 📞 Soporte técnico

Si tienes alguna pregunta sobre las pruebas de rendimiento, no dudes en contactar con nosotros:

- **Soporte técnico**: yaohui.zhu@seeed.cc
- **Discord**: [Únete a la comunidad](https://discord.gg/AbGuqJhDpQ)
- **Wiki**: [Consulta la base de conocimientos](https://wiki.seeedstudio.com/robotics_page/)

---

<p align="center">
  <strong>🤖 reBot-DevArm - Un brazo robótico de código abierto para todos los desarrolladores</strong>
</p>

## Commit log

2026-05-29 Add the English version of the DM power supply assembly steps and the link to the 3D printed parts to reBot_B601_DM/readme.md.
2026-06-06 docs: add gamepad teleop with IK to contributions table
    Document gamepad control with inverse kinematics and RViz visualization
    in the reBotArmController_ROS2 community contributions section.
2026-07-09 Opensource reBot Arm RS
    [1-BASE-PLATE.step, 1-CLIP.step, 1-COVER.step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]
2026-07-17 增加购物卡片
2026-07-17 修html 样式
2026-07-17 修 html 样式
2026-07-17 修改样式
2026-07-17 更新其他语种链接
2026-07-18 docs(es): add RS hardware Spanish README, refresh Spanish docs to es-ES, fix RS language links
    - Add hardware/reBot_B601_RS/README_es.md (Castilian Spanish BOM/assembly guide)
    - Fix the language-selector row in the RS en/fr/zh READMEs: links pointed to
    lowercase readme_*.md files copied from the DM folder (404 on GitHub) and to
    a Japanese version that does not exist in this folder; also fix the DM BOM
    cross-link case (README.md -> readme.md)
    - Refresh README_es.md to match the current English README (adds the official
    purchase block, the reBot Arm B601 RS section heading, and remaining
    untranslated cells) and normalise it to es-ES
    - Complete hardware/reBot_B601_DM/readme_es.md (mis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
2026-07-25 Change 'Buy now' to 'SeeedStudio Bazaar' link
    Updated purchase links for reBot Arm B601-DM in README.
2026-07-27 docs: correct XT30-to-XT60 adapter purchase details
    The previous Amazon listing points to an XT60 male-to-female extension cable, not the required XT30U female-to-XT60 male adapter.
    Update the affected B601-RS localizations and the B601-DM entries that reused the listing: use ASIN B0BY8PSHK6 where links are present, set the current price to $8.99, and remove unavailable 12 AWG and 50 cm requirements. Preserve the French README's existing plain-text Amazon reference.
2026-08-11 fix rs's bom
    [2-Motor_Back_Spacer.step]
2026-08-12 ci: pin star-history workflow actions to commit SHAs
    The scheduled workflow ran narayann7/star-history-action@main, a mutable
    branch reference, while holding a workflow-wide contents: write token. A
    composite action's steps execute in this repository's runner, so whatever
    sat on that branch at 00:17 UTC each day ran with permission to push to
    main.
    - Pin both actions to full commit SHAs (checkout v5.0.0, star-history
    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
2026-08-13 docs: fix broken purchase and wiki links, add link-check CI
    Every link in every markdown file was checked (203 unique external URLs,
    915 relative paths). Six classes of breakage, each repeated across the
    translated copies:
    - DM4310(V4) motor: seeedstudio p-6660 is 404 since the product was
    relisted. Now points at Damiao-4310-Actuator-Motor-p-6823, whose
    $120.00 price matches the BOM line.
    - AliExpress purchase link: pasted out of a Feishu sheet, so it pointed
    at Feishu's link-safety interstitial (now 404) and the paste duplicated
    part of the query string, closing the href attribute early. Replaced
    with the decoded destination.
    - IMU/gyroscope wiki link: no Sensor/IMU/ path exists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
2026-08-20 docs: point RS BOM links at README.md, not readme.md
    The weekly link check has been failing on main since 2026-08-17. Two
    links, in README_Fr.md and README_JP.md, target
    ./hardware/reBot_B601_RS/readme.md, but that directory holds README.md
    in uppercase — the RS folder uses README.md while the DM folder beside
    it uses readme.md. GitHub serves paths case-sensitively, so both 404.
    These slipped through review in #58 because that verification ran on a
    case-insensitive Windows filesystem, where readme.md resolves to
    README.md and reports as fine. The CI job runs on ubuntu-latest, which
    is why it caught them on its first scheduled run.
    Closes #60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
2026-08-21 docs: resync translated READMEs with the English source
    Four factual disagreements between README.md and its translations, each
    one English being updated and the copies not following:
    - README_zh.md gave DM max reach as 650 mm. Commit 065c9f2 corrected
    that to 767 mm in English on 2026-06-16 and Fr/JP/es followed; zh did
    not. 117 mm is enough to size a workcell wrong.
    - The RS Isaac Sim row was marked planned in zh, JP and Fr while linking
    to Seeed-Projects/reBot-Isaacsim in the same row. The work shipped;
    #47 is still open asking about it.
    - README_zh.md was missing the reSpeaker voice integration row that #39
    added everywhere else, so the Chinese roadmap had 12 rows against 13.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
2026-08-22 docs: sync DM hardware BOM sections across languages
    The five language versions of hardware/reBot_B601_DM had diverged to the
    point where what you can build depended on which one you read: 11, 11,
    12, 8 and 8 tables respectively, and 31, 31, 35, 9 and 29 links.
    - readme_fr.md and readme_jp.md had no power-supply assembly section at
    all. They stopped after a superseded 3-row BOM still listing a 12AWG
    cord and an XT30 16AWG cable, where the current BOM specifies an
    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
2026-08-27 Update the README: add 'Seeed reBot Arm & NVIDIA Isaac Sim-to-Real VLA Course' to the Interesting Community Projects section.
2026-08-27 Update the GIF link for 'Seeed reBot Arm & NVIDIA Isaac Sim-to-Real VLA Course' in the Interesting Community Projects section.

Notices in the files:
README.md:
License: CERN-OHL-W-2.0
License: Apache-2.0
